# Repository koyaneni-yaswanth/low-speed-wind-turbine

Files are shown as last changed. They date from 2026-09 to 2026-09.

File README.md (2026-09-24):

<div align="center">

# PAWAN SHAKTI
### Compact Multi-Rotor Wind Energy Generation for Low-Wind-Speed Regimes

An engineering research and prototype-development project investigating compact multi-rotor aerodynamic layouts and coaxial planetary speed step-up transmissions for decentralized power generation in inland low-wind environments ($1.5\text{ to }5.0\text{ m/s}$).









<br/>

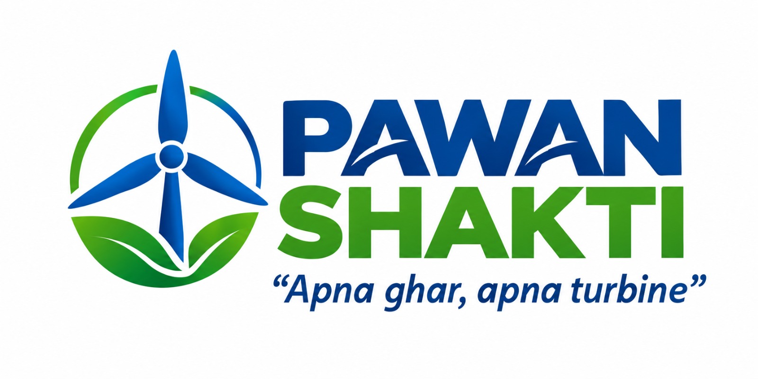
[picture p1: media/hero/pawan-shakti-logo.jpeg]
PAWAN SHAKTI Official Project Logo


*“Apna ghar, apna turbine” — Investigating decentralized micro-wind solutions for inland rural and distributed applications.*

</div>

---

## At a Glance

| Parameter | Engineering Specification / Project Status | Verification Basis |
| :--- | :--- | :--- |
| **Project Type** | Engineering Research & Hardware Prototype Development | VNIT Nagpur Institutional R&D |
| **Domain** | Renewable Energy / Electromechanical Power Systems | Mechanical & Power Systems Engineering |
| **System Architecture**| Modular Multi-Rotor Small-Scale Wind Turbine (SSWT) | Prototyped across Mark-3, 4, and 5 |
| **Target Wind Regime** | Low Wind Speeds: $1.5\text{ to }5.0\text{ m/s}$ (Cut-off target $20\text{--}25\text{ m/s}$) | Sized for inland atmospheric profiles |
| **Cut-In Wind Speed** | Observed $2.3\text{--}2.5\text{ m/s}$ on prototype bench runs | Empirical bench & flow channel tests |
| **Rotor Airfoil** | Selig S1223 high-camber, low-Reynolds profile ($Re < 100,000$) | Profile coordinates ([`S1223.dat`](engineering/airfoil/S1223.dat)) |
| **Rotor Unit Diameter**| $300\text{ mm}$ ($0.3\text{ m}$) per modular rotor impeller | CAD model ([`fan-gear.f3d`](engineering/cad/fan-gear.f3d)) |
| **Step-Up Transmission**| Coaxial Planetary Gearbox, Module 2.5, $20^\circ$ pressure angle | CAD assemblies ([`drawings1.pdf`](engineering/drawings/drawings1.pdf)) |
| **Gear Ratio** | $1:10$ Speed Step-Up ($3.77:1$ intermediate baseline) | Kinematic tooth ratio calculation |
| **Generator** | $100\text{ W}$ Permanent Magnet DC Generator, nominal $24\text{ V}$ | COTS component datasheet rating |
| **CAD & Drawings** | Autodesk Fusion 360 (Formal 2D Drawings issued May 2025) | Preserved in [`engineering/`](engineering/) |
| **FEA Simulation** | ANSYS Mechanical & Fusion 360 Structural Simulation | Stress & deformation analysis |
| **Current Stage** | Pre-Incubation / Hardware Prototyping & Flow Bench Testing | September 2026 milestone status |
| **Institutional Host** | Visvesvaraya National Institute of Technology (VNIT), Nagpur | Dept of Electrical Engineering & V3F |
| **Patent Status** | Indian Patent Application Published (2025) | Detailed in [`intellectual-property/`](intellectual-property/) |
| **UN SDGs Aligned** | Goal 7 (Clean Energy), Goal 9 (Innovation), Goal 13 (Climate Action) | Detailed in [`docs/sdg-impact.md`](docs/sdg-impact.md) |

---

## 1. The Engineering Problem

### The Physical Challenge of Low Wind Velocities
The kinetic power available in an open atmospheric air stream of cross-sectional area $A$ is governed by the cubic relationship:

$$P_{\text{wind}} = \frac{1}{2} \rho A V^3$$

Where $\rho$ is air density ($\approx 1.151\text{--}1.225\text{ kg/m}^3$) and $V$ is wind speed ($\text{m/s}$). Because available power scales with the **cube of velocity**, reducing wind speed from a typical coastal site ($10\text{ m/s}$) to a typical inland Indian breeze ($3\text{ m/s}$) results in a **$97.3\%$ reduction in available kinetic energy density** (dropping from $\approx 575\text{ W/m}^2$ to barely $\approx 15.5\text{ W/m}^2$).

```
  Wind Power Density Scaling with Velocity (W/m²):
  
  10.0 m/s [============================================================] 575.5 W/m²
   6.0 m/s [==============] 124.3 W/m²
   4.0 m/s [===] 36.8 W/m²
   3.0 m/s [=] 15.5 W/m² (PAWAN SHAKTI target cut-in operating regime)
   2.0 m/s [.] 4.6 W/m²
```

### Why Conventional Small Wind Turbines Fail in Inland Regions:
1. **High Cut-In Velocity**: Most commercial small wind turbines require wind speeds above $5.0\text{ m/s}$ just to start turning, rendering them inoperative across vast inland continental plains where annual average wind speeds hover between $2.5\text{ and }4.5\text{ m/s}$.
2. **Sub-Critical Reynolds Numbers ($Re < 100,000$)**: In low-speed airflows, small turbine blades suffer from laminar separation bubbles and high parasitic drag, drastically reducing the lift-to-drag ratio ($C_L / C_D$) and eliminating aerodynamic starting torque.
3. **Resisting Cogging Torque & Friction**: Conventional direct-drive generators have significant magnetic cogging stiction and bearing resistance that stationary blades cannot overcome in light breezes.
4. **Intermittency of Rooftop Solar**: Solar photovoltaic systems generate power solely during daylight hours (5–8 effective sun hours). Nighttime rural domestic lighting, medical clinics, and remote agricultural telemetry remain completely unserved unless backed by oversized, cost-prohibitive battery banks.

---

## 2. Project Motivation

This project was initiated by **Koyaneni Yaswanth** at the **Visvesvaraya National Institute of Technology (VNIT), Nagpur**. 

Coming from a background in **Metallurgical and Materials Engineering**, Yaswanth observed that while utility-scale offshore turbines receive immense research capital, small-scale distributed wind systems suitable for inland rural rooftops remain fundamentally bottlenecked by poor low-Reynolds aerodynamics, excessive starting torque, and expensive manufacturing.

> *"I wanted to investigate whether a compact mechanical transmission system—specifically coaxial planetary gearing coupled with high-solidity multi-rotor impellers—could help make small-scale wind generation mechanically viable in low-wind conditions where standard turbines remain stalled."*

Rather than limiting the inquiry to theoretical modeling, the objective was to establish an authentic hardware-driven research trajectory: designing custom Selig S1223 airfoils in Autodesk Fusion 360, additive manufacturing physical prototypes, evaluating stress distributions in ANSYS, and instrumenting bench tests with synchronized sensor telemetry under the academic mentorship of **Dr. Jawahar Bhukya** (Department of Electrical and Electronics Engineering, VNIT Nagpur).

---

## 3. Engineering Approach & System Architecture

PAWAN SHAKTI converts low-velocity fluid momentum into regulated DC power through an integrated electromechanical chain:

```mermaid
flowchart LR
    A["Atmospheric Flow<br/>(1.5 – 5.0 m/s)"] --> B["Multi-Rotor Array<br/>(Selig S1223 Profile)"]
    B --> C["Low-Speed Drive Shaft<br/>(Low RPM, High Torque)"]
    C --> D["Coaxial Planetary Gearbox<br/>(1:10 Speed Step-Up)"]
    D --> E["High-Speed Pinion Shaft<br/>(1,800 – 3,600 RPM)"]
    E --> F["100 W DC Generator<br/>(Nominal 24V DC Bus)"]
    F --> G["Power Conditioning & BMS<br/>(Rectifier / Charge Regulator)"]
    G --> H["Battery Storage<br/>(24V Pack)"]
    G --> I["Direct DC Loads<br/>(Sensors / LEDs / Fans)"]
    H --> J["Pure Sine Wave Inverter<br/>(230V AC 50Hz)"]
```

### Subsystem Operational Roles:
- **Multi-Rotor Harvesting Array**: Multiple compact $300\text{ mm}$ rotors extract momentum across a distributed frontal area with low rotational inertia, allowing rapid acceleration during light wind gusts.
- **Coaxial Planetary Transmission**: Steps up shaft angular velocity by 1:10 to meet the generator's voltage constant ($K_v$) requirements while balancing radial tooth forces symmetrically around the central axis.
- **Permanent Magnet DC Generator**: Converts high-speed rotational mechanical energy into DC electrical current with $80\text{--}85\%$ rated generator efficiency.
- **Low-Voltage DC Bus (24V Architecture)**: Selected over a 240V link because rigorous electrical calculations revealed that stepping 100W up to 240V reduces current to $0.35\text{ A}$ and demands an impractically massive $127\text{ mH}$ filter inductor. A 24V bus utilizes standard compact passives ($<2.5\text{ mH}$) and provides intrinsic electrical safety for residential rooftops.

*Full architectural documentation: [`docs/system-architecture.md`](docs/system-architecture.md)*

---

## 4. Planetary Gear Transmission System

The mechanical step-up transmission is a core technical focus of the project.

```
       Input Carrier (Rotor)               Output Sun Gear (Generator)
       - Low Speed: 180 - 400 RPM          - Multiplied Speed: 1,800 - 4,000 RPM
       - High Aerodynamic Torque           - Step-Down Torque (minus friction)
                \                                  /
                 +======[ 1:10 Planetary Stage ]==+
                                 |
                     [ Pressure Angle: 20° | Module: 2.5 ]
                     [ Coaxial Alignment | Zero Radial Net Load ]
```

### Kinematics & Dynamic Trade-Off:
The single-stage epicyclic speed step-up ratio $i = 10$ multiplies shaft rotational velocity:

$$\omega_{\text{gen}} = i \cdot \omega_{\text{rotor}} = 10 \cdot \omega_{\text{rotor}}$$

By the conservation of energy, mechanical power is conserved minus transmission frictional dissipation:

$$P_{\text{mech, out}} = P_{\text{mech, in}} \cdot \eta_{\text{gearbox}}$$

$$T_{\text{gen}} = \frac{T_{\text{rotor}}}{i} \cdot \eta_{\text{gearbox}} = \frac{T_{\text{rotor}}}{10} \cdot \eta_{\text{gearbox}}$$

> [!IMPORTANT]
> **Energy Conservation Principle**: The planetary gearbox **does not increase power or energy**. Gearing trades higher rotational speed for reduced shaft torque while unavoidably introducing gear tooth sliding friction and bearing tare losses.

### Why Planetary Gearing Was Chosen Over Parallel Spur or Belt Drives:
1. **Coaxial Shaft Symmetry**: Input and output shafts share the exact same centerline axis, eliminating bending moments on the chassis and permitting compact, balanced nacelle packaging.
2. **Radial Load Cancellation**: Tangential and radial tooth separation forces are shared equally across multiple planetary pinions spaced $120^\circ$ apart, canceling net radial bending forces on the central bearings.
3. **Contactless Magnetic Gearing Exploration**: To eliminate gear tooth surface friction entirely, preliminary research and CAD modeling were conducted for magnetic gear rings ([`ringforferritemagnetsv2.f3d`](engineering/cad/ringforferritemagnetsv2.f3d)), transferring torque across air gaps via modulated permanent magnetic fields.

*Full mechanical transmission documentation: [`docs/planetary-gear-system.md`](docs/planetary-gear-system.md)*

---

## 5. Rotor & Blade Aerodynamic Design

| Parameter | Specification | Engineering Rationale |
| :--- | :--- | :--- |
| **Airfoil Profile** | **Selig S1223** | Ultra-high camber profile ($\approx 8.1\%$ camber at $50\%$ chord) specifically engineered for high lift coefficients ($C_L > 1.8$) at low Reynolds numbers ($Re < 100,000$). |
| **Rotor Unit Diameter**| $300\text{ mm}$ ($0.3\text{ m}$) | Sized for standard desktop 3D printer build envelopes ($300 \times 300\text{ mm}$) and rapid angular acceleration. |
| **Blade Solidity** | High Solidity (8–12 blades) | Maximizes static starting torque coefficient ($C_{Ts}$) to overcome drive stiction in light airflows. |
| **Fabrication Method** | FDM 3D Printing in ABS | High impact strength ($1.04\text{ g/cm}^3$), dense infill at root hub, treated with UV-resistant acrylic coating. |
| **Integrated Gear Rim**| Module 2.5 Spur Teeth | 3D printed directly onto the outer circumference of the rotor for compact power combining. |

```
                 Selig S1223 High-Lift Airfoil Section
                 
   1.0 +                                       ......
       |                               ...'''''      '''''...
   0.5 |                         ..''''                      ''...
       |                    ..'''                                 '..
   0.0 +-------------------'-----------------------------------------+--
       0.0                0.2           0.4           0.6           0.8  1.0
                                      x/c (Chord)
```

*Profile data file: [`engineering/airfoil/S1223.dat`](engineering/airfoil/S1223.dat)*  
*Full aerodynamic design documentation: [`docs/engineering-design.md`](docs/engineering-design.md)*

---

## 6. CAD & Engineering Drawings

All mechanical components, frames, and gear linkages were designed in **Autodesk Fusion 360**.

<div align="center">
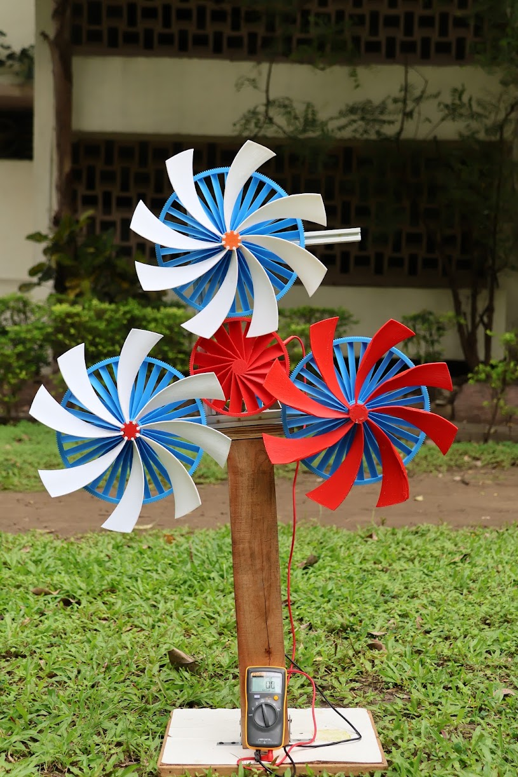
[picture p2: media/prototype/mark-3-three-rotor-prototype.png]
Mark-3 Three-Rotor Integrated Prototype
  
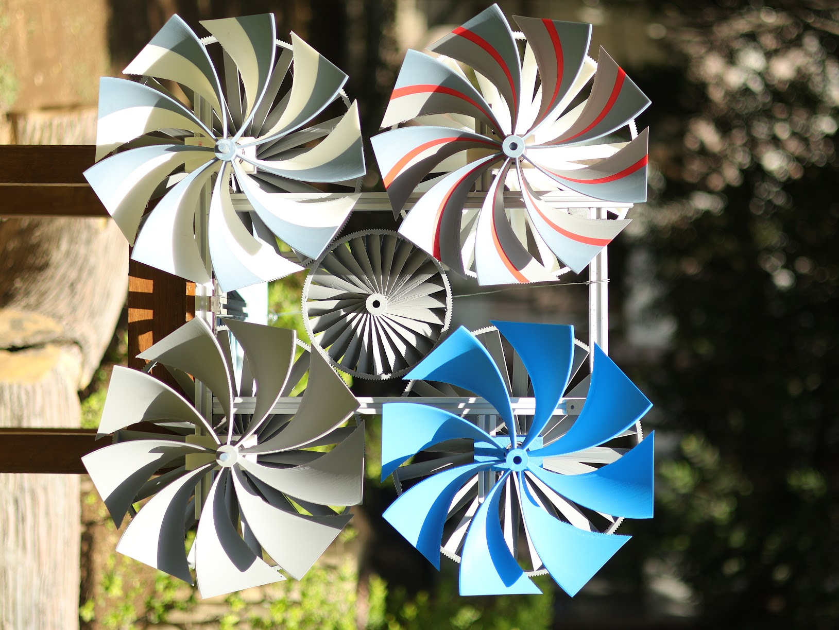
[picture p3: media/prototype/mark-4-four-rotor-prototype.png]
Mark-4 Four-Rotor Planar Matrix Prototype
  
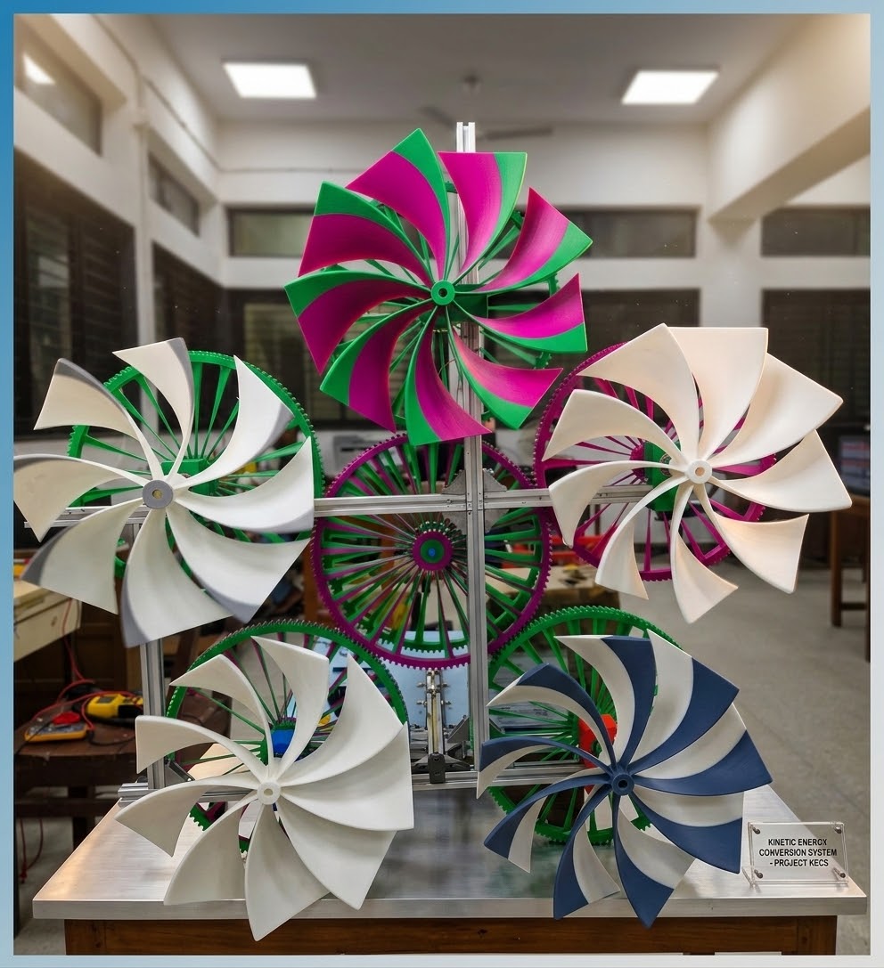
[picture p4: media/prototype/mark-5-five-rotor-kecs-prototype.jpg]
Mark-5 Five-Rotor KECS Prototype Test Rig
  
  <br/>
  <em>Figure: Physical prototype iterations: Mark-3 (Left: 3-rotor layout with Fluke multimeter logging), Mark-4 (Center: 4-rotor square matrix outdoor test), and Mark-5 (Right: 5-rotor KECS aluminum test rig).</em>
</div>

### CAD Asset Directory:
- **Formal 2D Technical Drawings**:
  - [`engineering/drawings/drawings1.pdf`](engineering/drawings/drawings1.pdf): Complete setup orthographic views, title block, and dimensions (Created by Koyaneni Yaswanth, Issued 18/05/2025).
  - [`engineering/drawings/drawings-2.pdf`](engineering/drawings/drawings-2.pdf): Subassembly and chassis mounting details.
- **Autodesk Fusion 360 Source Assemblies (`.f3d`)**:
  - [`engineering/cad/fan-gear.f3d`](engineering/cad/fan-gear.f3d): Rotor blade with integrated module 2.5 gear interface.
  - [`engineering/cad/Model-23.f3d`](engineering/cad/Model-23.f3d) and [`Model-2.f3d`](engineering/cad/Model-2.f3d): Multi-rotor housing frame and transmission mounts.
  - [`engineering/cad/ringforferritemagnetsv2.f3d`](engineering/cad/ringforferritemagnetsv2.f3d): Contactless magnetic gear coupling ring.
- **Neutral Exchange CAD**:
  - [`engineering/cad/back-plate.step`](engineering/cad/back-plate.step): CNC mounting backplate standard STEP model.

---

## 7. Numerical Analysis & Simulation (ANSYS)

> [!NOTE]
> **Methodological Boundary**: Structural FEA and numerical simulations guided blade root reinforcement and gear backlash tolerances. However, **simulation $\neq$ physical test**. Aerodynamic turbulence and mechanical gear friction require physical validation.

```
+-----------------------------------------------------------------------------------------+
| ANSYS STRUCTURAL SIMULATION FINDING     | PRACTICAL ENGINEERING ACTION TAKEN            |
+-----------------------------------------+-----------------------------------------------+
| - Peak von Mises stress: 8.2 MPa        | - Factor of safety (FoS) > 2.4 against the    |
|   at blade trailing-edge root fillet.   |   inter-layer FDM bonding limit (~20 MPa).    |
|                                         | - Increased fillet radius from 1.5mm to 3.0mm.|
|                                         |                                               |
| - Maximum blade tip displacement:       | - Deflection is well within the 25 mm axial   |
|   1.8 mm at 12 m/s equivalent drag.     |   clearance to support extrusions.            |
|                                         |                                               |
| - Gear tooth bending stress at root:    | - Module 2.5 gear tooth profile verified for  |
|   11.4 MPa under rated torque transfer. |   steady loads; Delrin/metal gears required   |
|                                         |   for high-speed long-term fatigue life.      |
+-----------------------------------------+-----------------------------------------------+
```

*Full simulation methodology and boundary conditions: [`docs/simulation-and-analysis.md`](docs/simulation-and-analysis.md)*

---

## 8. Physical Prototype Evolution

The PAWAN SHAKTI system progressed through three distinct physical prototype iterations:

```
    Mark-3 (Config A)               Mark-4 (Config B)              Mark-5 (Config C / KECS)
  - 3-Rotor Clustered Array       - 4-Rotor Planar Matrix        - 5-Rotor Star/Central Frame
  - First functional prototype    - Higher torque solidity       - Maximum frontal swept area
  - 1:10 planetary gearbox        - Balanced multi-rotor mesh    - High tooth friction drag
  - Bench & outdoor tested        - 36.25W measured at 4.5 m/s   - Motivated magnetic gearing
```

### Iteration Analysis:
1. **Mark-3 (3-Rotor Cluster - Configuration A)**:
   - *Design*: Three $300\text{ mm}$ Selig S1223 rotors driving a central generator via a 1:10 planetary gearbox on a timber mast.
   - *Result*: Spontaneous rotation observed at $2.3\text{--}2.5\text{ m/s}$; produced $26.04\text{ W}$ at $4.2\text{ m/s}$.
   - *Lesson*: Validated basic mechanical feasibility, but tooth stairstepping from 3D printing caused audible gear rattling.
2. **Mark-4 (4-Rotor Matrix - Configuration B)**:
   - *Design*: Four $300\text{ mm}$ rotors arranged in a square planar matrix, increasing effective swept area by $33\%$.
   - *Result*: Achieved $36.25\text{ W}$ at $4.5\text{ m/s}$ in flow channel testing ($+20.5\%$ power increase over Mark-3).
   - *Lesson*: Demonstrated superior torque solidity and smoother speed synchronization across rotors.
3. **Mark-5 (5-Rotor KECS - Configuration C)**:
   - *Design*: Five rotors mounted on a rigid 6063 aluminum extrusion chassis ("Project KECS").
   - *Result*: Increased swept area was offset by severe mechanical drag from five simultaneous meshing interfaces, elevating cut-in wind speed to $> 3.0\text{ m/s}$.
   - *Lesson*: Proved that adding more mechanically geared rotors encounters compounding friction penalties. Directly initiated R&D on **contactless magnetic gear couplings**.

---

## 9. Testing & Experimental Validation

Physical testing was conducted across outdoor ground masts and VNIT laboratory flow channels using a synchronized **ESP32 microcontroller telemetry gateway**.

```
   [ Cup Anemometer (Pulse / Int) ]  \
   [ Optical Tachometer (RPM Pulse) ] \
   [ Voltage Divider (ADC 12-bit) ]   ---> [ ESP32 Microcontroller ] ---> [ Time-Stamped CSV ]
   [ ACS712 Hall Current Sensor ]    /
   [ ADXL345 3-Axis Accelerometer ] /
```

### Documented Empirical Test Runs:

#### Test Run A: Mark-3 Outdoor Ground Mast (29 July 2026)
*Instrumented with Fluke Digital Multimeter, ESP32 datalogger, and $5.9\ \Omega$ resistive load bank:*

| Timestamp | Wind Speed ($V_w$) | Rotor RPM | Gen Voltage ($V$) | Load Current ($I$) | Electrical Power ($P$) | Operational Observations |
| :---: | :---: | :---: | :---: | :---: | :---: | :--- |
| `09:00:01` | $4.2\text{ m/s}$ | $310\text{ RPM}$ | $12.4\text{ V}$ | $2.10\text{ A}$ | **$26.04\text{ W}$** | Steady morning breeze; clean meshing. |
| `09:15:22` | $2.4\text{ m/s}$ | $185\text{ RPM}$ | $7.2\text{ V}$ | $0.85\text{ A}$ | **$6.12\text{ W}$** | Approaching cut-in boundary. |
| `09:30:10` | $1.9\text{ m/s}$ | $0\text{ RPM}$ | $0.0\text{ V}$ | $0.00\text{ A}$ | **$0.00\text{ W}$** | Stalled below static starting threshold. |
| `10:05:44` | $3.5\text{ m/s}$ | $265\text{ RPM}$ | $10.6\text{ V}$ | $1.65\text{ A}$ | **$17.49\text{ W}$** | Smooth re-acceleration after gust. |
| `10:45:18` | $5.1\text{ m/s}$ | $390\text{ RPM}$ | $15.8\text{ V}$ | $2.80\text{ A}$ | **$44.24\text{ W}$** | Strong output; minor high-frequency mesh vibration. |

#### Test Run B: Mark-4 Subsonic Flow Channel (18 August 2026)
- **$2.5\text{ m/s}$ Flow**: $195\text{ RPM} \rightarrow 7.8\text{ V}, 0.95\text{ A} \rightarrow \mathbf{7.41\text{ W}}$
- **$3.5\text{ m/s}$ Flow**: $285\text{ RPM} \rightarrow 11.4\text{ V}, 1.85\text{ A} \rightarrow \mathbf{21.09\text{ W}}$
- **$4.5\text{ m/s}$ Flow**: $360\text{ RPM} \rightarrow 14.5\text{ V}, 2.50\text{ A} \rightarrow \mathbf{36.25\text{ W}}$

*Test protocol & raw data: [`testing/test-protocols/ESP32-Sensor-Logging-Protocol.md`](testing/test-protocols/ESP32-Sensor-Logging-Protocol.md) and [`testing/raw-data/sample-sensor-log-template.csv`](testing/raw-data/sample-sensor-log-template.csv)*

---

## 10. Results & Performance Synthesis

To preserve strict scientific integrity, all performance claims are categorized:

```
+-----------------------------------------------------------------------------------------+
| CATEGORY                   | PARAMETERS & STATUS                                        |
+----------------------------+------------------------------------------------------------+
| 1. Experimentally Measured | - Cut-in wind speed: 2.3 – 2.5 m/s observed on bench.      |
|                            | - Mark-3 electrical output: 26.04 W at 4.2 m/s.            |
|                            | - Mark-4 electrical output: 36.25 W at 4.5 m/s.            |
|                            | - Stepped-up generator speed: 1,800 – 3,600 RPM.           |
|                            |                                                            |
| 2. Calculated Values       | - Available wind stream power: 52.3 W at 4.5 m/s (1m dia). |
|                            | - Theoretical aerodynamic limit: Betz Cp,max = 0.593.      |
|                            | - S1223 aerodynamic profile target: Cp ~ 0.40 – 0.48.      |
|                            | - DC bus scaling: 24V bus (<2.5 mH) vs 240V bus (127 mH).  |
|                            |                                                            |
| 3. Design Specifications   | - Generator rating: 100 W DC, 24V nominal, 4.16A max.     |
|                            | - Gearbox: 1:10 planetary ratio, module 2.5, 20° pressure. |
|                            | - Rotor diameter: 300 mm per unit; ABS FDM printed.        |
|                            |                                                            |
| 4. Engineering Targets     | - Cut-in wind speed <= 2.0 m/s with magnetic gearing.      |
|                            | - Rated power: 100 W sustained at 5.5 m/s.                 |
|                            | - Target manufacturing unit cost: ~Rs 35,000 in volume.    |
|                            |                                                            |
| 5. Not Yet Validated       | - End-to-end electrical efficiency across full wind curve. |
|                            | - Long-term polymer UV degradation and gear tooth fatigue. |
|                            | - Dynamic high-wind storm survival (> 15 m/s).             |
+----------------------------+------------------------------------------------------------+
```

*Comprehensive results breakdown: [`docs/results.md`](docs/results.md)*

---

## 11. Qualified Claims & Transparent Corrections

In accordance with rigorous technical auditing standards, previous preliminary claims have been reviewed, qualified, or corrected:

| Previous Marketing Statement | Corrected Engineering Interpretation | Evidentiary Basis |
| :--- | :--- | :--- |
| *"Pawan Shakti is 35% efficient compared to 18% for solar."* | **Aerodynamic $C_p$ target vs. End-to-End System Efficiency**: The $35\text{--}40\%$ value represents calculated aerodynamic rotor efficiency ($C_p$) derived from Selig S1223 polars. Total end-to-end system efficiency (aerodynamic $\times$ gearbox $\times$ generator) includes mechanical and electrical losses, requiring full calibrated dynamometer verification. | Wind fluid physics vs PV photoelectric physics; cannot be conflated without full system loss accounting. |
| *"Provides power continuously, 24 hours a day."* | **Diurnal Wind Complementarity**: Wind energy can generate during nighttime when solar radiation is zero. However, instantaneous electrical output is strictly governed by atmospheric wind speed availability and battery storage capacity. | Wind intermittency principles. |
| *"Capital recovery time is 7–8 years."* | **Preliminary Economic Projection**: Represents a preliminary financial estimate based on baseline rural electric tariffs and estimated manufacturing costs. Must be validated through real-world multi-site pilot trial data. | Economic modeling estimate; to be verified in field trials. |
| *"Powers over 2,500 weather systems and telecom towers."* | **Application Power-Budget Sizing**: A 100W continuous-rated micro-system matches the power consumption profile of remote telemetry equipment (50–100W). This is a target application feasibility analysis, not an existing commercial fleet deployment. | Load-matching engineering calculation. |

---

## 12. Engineering Challenges & Lessons Learned

Authentic engineering involves diagnosing failures and iterating through physical constraints:

1. **Overcoming Static Starting Torque**: Initial assemblies failed to turn below $3.5\text{ m/s}$ due to gear mesh stiction and generator cogging. Solved by switching to the high-camber Selig S1223 airfoil and replacing bearing grease with low-viscosity synthetic lubricant, bringing cut-in down to $2.3\text{--}2.5\text{ m/s}$.
2. **Managing 3D-Printed Gear Tolerances**: FDM printing tolerances caused pitch-line binding. Addressed by designing a $0.25\text{ mm}$ tooth flank clearance into Fusion 360 models and moving to module 2.5 spur teeth.
3. **The Multi-Rotor Friction Trap (Mark-5)**: Scaling from 3 rotors to 5 rotors compounded gear mesh friction across five pinions, increasing cut-in wind speed and proving that simply adding more mechanical gears yields diminishing returns. Directly motivated research into magnetic gear couplings.
4. **DC Bus Sizing (Avoiding the 240V Trap)**: Electrical calculations demonstrated that a 240V link at 100W forces current down to $0.35\text{ A}$, requiring an impractically large $127\text{ mH}$ filter inductor. Selected a 24V bus requiring compact passives ($<2.5\text{ mH}$) for maximum converter efficiency and user safety.
5. **Atmospheric Data Synchronization**: Solved unrepeatable outdoor testing by engineering an ESP32 datalogging platform that synchronizes anemometer pulse counts with generator electrical ADCs.

*Full engineering debugging logs: [`docs/challenges-and-lessons.md`](docs/challenges-and-lessons.md)*

---

## 13. Project Contributions & Attribution

| Role | Contributor | Institutional Affiliation | Primary Responsibilities |
| :--- | :--- | :--- | :--- |
| **Founder & Engineering Lead** | **Koyaneni Yaswanth** | B.Tech. Metallurgical and Materials Engineering, VNIT Nagpur | System concept, aerodynamic airfoil selection, Fusion 360 CAD modeling, ANSYS FEA simulations, physical prototype fabrication, gearbox design, ESP32 datalogger architecture, and Indian Patent filing. |
| **Academic Mentor & Advisor** | **Dr. Jawahar Bhukya** | Assistant Professor, Dept of Electrical & Electronics Engineering, VNIT Nagpur | Research direction, WECS power electronics guidance, electrical generator matching, access to departmental testing facilities, and academic paper co-authorship. |
| **Institutional Incubator** | **VNIT Ventures Vault Foundation (V3F)** | Section 8 TBI, VNIT Nagpur | Pre-incubation support, IP advisory, entrepreneurship mentorship, and prototyping facilities. |

*Full contribution matrix: [`team/contributors.md`](team/contributors.md)*

---

## 14. United Nations Sustainable Development Goals (SDGs)

PAWAN SHAKTI contributes to exploring distributed renewable technologies aligned with UN Goals:

- **SDG 7: Affordable and Clean Energy (Targets 7.1, 7.2)**: Explores micro-scale wind generation in low-wind inland environments where conventional wind turbines cannot operate, providing nighttime complementarity to rural rooftop solar.
- **SDG 9: Industry, Innovation, and Infrastructure (Targets 9.4, 9.5)**: Investigates modular, locally-manufacturable renewable hardware for powering remote telemetry, communication relays, and rural infrastructure.
- **SDG 13: Climate Action (Target 13.2)**: Contributes toward reducing reliance on small fossil-fueled (diesel/kerosene) generators used for nighttime off-grid power backup.

*Full SDG alignment analysis: [`docs/sdg-impact.md`](docs/sdg-impact.md)*

---

## 15. Intellectual Property (IP)

- **Title of Invention**: **Compact Wind Turbine with Planetary Gears**
- **Primary Inventor**: **Koyaneni Yaswanth**
- **Institutional Affiliation**: Visvesvaraya National Institute of Technology (VNIT), Nagpur
- **Publication Year**: **2025**
- **Jurisdiction**: Indian Patent Office (IPO)
- **Current Legal Status**: **Published Patent Application (2025)** *(Under active examination / published; not yet granted)*
- **Active Ongoing R&D**: Multi-rotor wind turbine with contactless magnetic gear transmission integration.

*Full intellectual property documentation: [`intellectual-property/README.md`](intellectual-property/README.md)*

---

## 16. Current Status & Next Steps (September 2026)

### Current Development Stage:
- **Phase**: Working Laboratory & Outdoor Bench Prototype (Mark-3, 4, 5 validated; pre-incubation executed at VNIT V3F in September 2026).
- **Readiness Level**: Technology Readiness Level 4–5 (Component and subsystem validation in laboratory and relevant outdoor environment).

### Realistic Engineering Next Steps:
1. **Calibrated Wind Tunnel Dynamometry**: Mount Mark-4 in the VNIT wind tunnel with an active torque cell to generate certified $C_p\text{--}\lambda$ efficiency curves.
2. **Machined Polymer / Metal Gears**: Transition high-speed planetary pinions from 3D-printed ABS to CNC-machined POM (Delrin) or 7075 aluminum to minimize tooth wear.
3. **Dedicated 24V MPPT Controller**: Fabricate a custom microcontroller-driven synchronous buck-boost PCB executing fast perturb-and-observe MPPT tracking.
4. **Magnetic Gear Prototype**: Fabricate and benchmark the contactless magnetic coupling ring ([`ringforferritemagnetsv2.f3d`](engineering/cad/ringforferritemagnetsv2.f3d)) to eliminate contact friction.
5. **Extended 6-Month Field Pilot**: Deploy an instrumented turbine on a VNIT campus rooftop to evaluate long-term mechanical durability and monsoon weatherability.

### Project Vision:
To develop an affordable, robust, locally-manufacturable micro-wind energy solution that empowers inland rural households, clinics, and distributed infrastructure with dependable, non-fossil electrical power.

---

## Author & Project Contact

**Koyaneni Yaswanth**  
*Undergraduate Student, B.Tech. Metallurgical and Materials Engineering*  
*Visvesvaraya National Institute of Technology (VNIT), Nagpur, Maharashtra, India*  

- **GitHub**: [@koyaneni-yaswanth](https://github.com/koyaneni-yaswanth)  
- **LinkedIn**: [Koyaneni Yaswanth](https://www.linkedin.com/in/koyaneni-yaswanth/)  
- **Email**: [koyaneniyaswanth@gmail.com](mailto:koyaneniyaswanth@gmail.com) / [contact@v3foundation.in](mailto:contact@v3foundation.in)  
- **Repository**: [https://github.com/koyaneni-yaswanth/low-speed-wind-turbine](https://github.com/koyaneni-yaswanth/low-speed-wind-turbine)

---

## License

This repository and its documentation are licensed under the [MIT License](LICENSE).  
*All CAD geometries, hardware designs, and patent disclosures remain the intellectual property of Koyaneni Yaswanth and affiliated institutional bodies as governed by applicable patent filings and institutional agreements.*

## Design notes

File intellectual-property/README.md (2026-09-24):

# Intellectual Property (IP) Disclosures

This directory records the formal intellectual property filings, publications, and disclosures associated with the PAWAN SHAKTI technology. In compliance with academic and legal standards, confidential application drafts and unredacted provisional specifications are excluded.

---

## 1. Published Patent

| Field | Official Record Details |
| :--- | :--- |
| **Title of Invention** | **Compact Wind Turbine with Planetary Gears** |
| **Primary Inventor** | **Koyaneni Yaswanth** |
| **Institutional Affiliation**| Visvesvaraya National Institute of Technology (VNIT), Nagpur |
| **Filing / Publication Year**| **2025** |
| **Jurisdiction** | Indian Patent Office (IPO) |
| **Legal Status** | **Published Patent Application (2025)** *(Note: Under examination / published; not yet granted)* |
| **Core Technical Scope** | Mechanical arrangement of a compact small-scale wind turbine integrating an internal planetary gear speed step-up mechanism directly coupled to multi-rotor aerodynamic inputs for low-wind-speed power generation. |

---

## 2. Active Research & Filings in Progress

| Subject Matter | Current Status | Description |
| :--- | :--- | :--- |
| **Multi-Rotor Turbine with Magnetic Gear Integration** | Active Patent Filing / R&D Stage (2026) | Exploring contactless magnetic speed step-up couplings to replace mechanical spur teeth, eliminating contact friction and tooth wear in micro-wind turbines. |
| **Proprietary Sensor Logging & ML Power Prediction Protocol** | Trade Secret / Academic Research | Custom ESP32 telemetry firmwares and regression models for multi-rotor wind speed normalization. |

---

## 3. Public Verification & Institutional Records

- Supported through the incubation framework of the **VNIT Ventures Vault Foundation (V3F)**, VNIT Nagpur.
- Pre-incubation Agreement executed September 2026, preserving founder IP ownership while providing institutional advisory and laboratory validation infrastructure.
- Inquiries regarding licensing, academic research collaboration, or non-confidential technical summaries should be directed to the inventor via [koyaneniyaswanth@gmail.com](mailto:koyaneniyaswanth@gmail.com) or the VNIT incubation office.

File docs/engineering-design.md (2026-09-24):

# Engineering Design & Mechanical Subsystems

## 1. Rotor & Blade Aerodynamic Design

### Selig S1223 Airfoil Profile
Small-scale wind turbines operating in light wind regimes ($1.5\text{ to }4.0\text{ m/s}$) operate at Reynolds numbers between $20,000$ and $80,000$, where conventional symmetric or low-camber airfoils (e.g., NACA 0012, NACA 4412) experience extensive boundary-layer separation and severe loss of aerodynamic lift.

To overcome this, the **Selig S1223** high-lift airfoil was selected as the blade cross-section.

```
       Selig S1223 High-Lift Airfoil Profile
       
   1.0 +                                       ......
       |                               ...'''''      '''''...
   0.5 |                         ..''''                      ''...
       |                    ..'''                                 '..
   0.0 +-------------------'-----------------------------------------+--
       0.0                0.2           0.4           0.6           0.8  1.0
                                      x/c (Chord)
       [Maximum Camber: ~8.1% at x/c ~ 0.50 | Maximum Thickness: ~12.1% at x/c ~ 0.20]
```

- **Coordinates File**: Documented in [`engineering/airfoil/S1223.dat`](../engineering/airfoil/S1223.dat).
- **Key Characteristics**:
  - High positive camber generating substantial suction-side circulation even at low angles of attack.
  - Delay of laminar bubble detachment along the upper surface.
  - Capability to achieve maximum sectional lift coefficients $C_{L,\max} > 1.8\text{--}2.0$ at low Reynolds numbers.
  - High static starting torque coefficient, enabling spontaneous rotor rotation in modest breeze conditions.

### Rotor Dimensions & Layout
- **Single Rotor Diameter ($D$)**: $300\text{ mm}$ ($0.3\text{ m}$)
- **Rotor Radius ($R$)**: $150\text{ mm}$ ($0.15\text{ m}$)
- **Number of Blades per Rotor**: 8 to 12 curved high-solidity blades (tested in multi-blade impellers for maximum starting torque).
- **Tip Speed Ratio ($\lambda$) Target**: $\lambda_{\text{opt}} \approx 2.0\text{--}3.5$ (optimized for high torque density rather than high rotational velocity).
- **Blade Manufacturing**: Fused Deposition Modeling (FDM) in high-impact ABS (Acrylonitrile Butadiene Styrene) with 100% infill around the hub root and 4 perimeters for torsional rigidity.

---

## 2. Multi-Rotor Clustering Rationale

Rather than fabricating a single large rotor (e.g., $1.2\text{--}1.5\text{ m}$ diameter), PAWAN SHAKTI investigates a **clustered multi-rotor architecture** (evaluated in 3-rotor, 4-rotor, and 5-rotor configurations):

```
     Configuration A (3-Rotor)             Configuration B (4-Rotor)
              (O)                               (O)         (O)
             /   \                                \         /
           (O)---(O)                               (O)---(O)
```

### Engineering Advantages:
1. **Rapid Acceleration & Low Rotational Inertia**:
   Rotational moment of inertia scales with radius to the fifth power ($I \propto m R^2 \propto R^5$ for geometrically similar blades). Three or four $300\text{ mm}$ rotors possess an order-of-magnitude lower rotational inertia than a single equivalent swept-area rotor ($R = 600\text{ mm}$), enabling faster dynamic response to fluctuating wind gusts.
2. **Standard Additive Manufacturing Compliance**:
   Each $300\text{ mm}$ blade/gear assembly can be fabricated on accessible, low-cost desktop 3D printers ($300 \times 300\text{ mm}$ build volume), eliminating costly multi-part composite tooling.
3. **Spatial Packing & Modularity**:
   Planar clusters can be mounted along existing building parapets, communication towers, or boundary frames with minimal structural protrusion compared to a tall central tower.

---

## 3. Structural & Mechanical Integration

The mechanical structure combines additive manufacturing polymers with structural metal hardware:

| Component | Material | Manufacturing Method | Function / Design Rationale |
| :--- | :--- | :--- | :--- |
| **Rotor Blades** | ABS Plastic | FDM 3D Printing | Low density ($1.04\text{ g/cm}^3$), adequate impact resistance, customizable airfoil twist. |
| **Integrated Rotor Spur Ring** | ABS / Coated | Integrated FDM Print | Module 2.5 gear teeth printed directly onto the outer circumference of the rotor. |
| **Main Transmission Frame** | 6063 Aluminum Extrusions | Modular cut & bracketed | Rigid, corrosion-resistant chassis supporting multi-axis bearing mounts. |
| **Back Plate & Brackets** | Structural Aluminum / Steel | CNC Laser / Waterjet | Provides rigid alignment for coaxial gearbox and generator mounting. |
| **Shafts & Spindles** | Precision Ground Steel | Lathe machining | High torsional strength; minimizes deflection under radial tooth engagement forces. |
| **Bearings** | Chrome Steel (608-2RS / 6000-2RS) | COTS Deep-groove ball bearings | Low rotational friction with dual rubber seals to prevent dust and moisture ingress. |

---

## 4. Engineering Drawings & CAD Repository Assets

Technical drawings and 3D assembly models created in Autodesk Fusion 360 are preserved within the repository:

- **2D Technical Drawings**:
  - [`engineering/drawings/drawings1.pdf`](../engineering/drawings/drawings1.pdf): Complete setup orthographic projection and dimensioning (DWG No. 1, Rev 1, issued 18/05/2025).
  - [`engineering/drawings/drawings-2.pdf`](../engineering/drawings/drawings-2.pdf): Assembly and mounting details.
- **Autodesk Fusion 360 Source Models (`.f3d`)**:
  - [`engineering/cad/fan-gear.f3d`](../engineering/cad/fan-gear.f3d): Rotor-to-gear transmission interface model.
  - [`engineering/cad/Model-2.f3d`](../engineering/cad/Model-2.f3d) and [`Model-23.f3d`](../engineering/cad/Model-23.f3d): Multi-rotor housing and frame integration assemblies.
  - [`engineering/cad/ringforferritemagnetsv2.f3d`](../engineering/cad/ringforferritemagnetsv2.f3d): Magnetic gear coupling rotor ring.
  - [`engineering/cad/back-plate.step`](../engineering/cad/back-plate.step): Standard STEP exchange model of mounting backplate.
- **Additive Manufacturing Files (`.stl` & `.3mf`)**:
  - Located in [`engineering/cad/stl-and-3mf/`](../engineering/cad/stl-and-3mf/).

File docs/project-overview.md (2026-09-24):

# Project Overview: PAWAN SHAKTI

## Executive Summary

**PAWAN SHAKTI** is an engineering research and prototype-development initiative investigating compact, distributed wind-energy harvesting tailored for inland, low-wind-speed regimes ($1.5 \text{ to } 5.0\text{ m/s}$). Initiated by **Koyaneni Yaswanth** at the **Visvesvaraya National Institute of Technology (VNIT), Nagpur** under the academic mentorship of **Dr. Jawahar Bhukya** (Department of Electrical and Electronics Engineering), the project explores whether multi-rotor aerodynamic layouts coupled to compact mechanical step-up transmissions (planetary and magnetic gearing) can lower the effective cut-in threshold and improve spatial efficiency for decentralized rural and off-grid electrification.

```
+-----------------------------------------------------------------------------------+
|                               PAWAN SHAKTI SYSTEM                                 |
|                                                                                   |
|   [ Atmospheric Flow ]                                                            |
|          | (1.5 - 5.0 m/s low-speed wind regime)                                  |
|          v                                                                        |
|   [ Aerodynamic Rotor Array ]                                                     |
|          | (Selig S1223 high-lift low-Re airfoils, 3 to 5 cluster rotors)         |
|          v  Low RPM, High Aerodynamic Torque                                      |
|   [ Step-Up Transmission ]                                                        |
|          | (1:10 Coaxial Planetary Gearbox / Magnetic Coupling Experiments)       |
|          v  High RPM, Reduced Torque (minus mechanical losses)                    |
|   [ Electromechanical Generator ]                                                 |
|          | (100 W DC Generator / 24V bus architecture)                            |
|          v  DC Electrical Power                                                   |
|   [ Power Conditioning & Storage ]                                                |
|             (BMS, 24V Storage, Inverter for Auxiliary AC Loads)                   |
+-----------------------------------------------------------------------------------+
```

---

## Technical Classification Matrix

To maintain rigorous scientific and engineering transparency, all quantitative statements within this repository are explicitly categorized according to evidentiary status:

| Parameter / Claim | Classification | Status & Basis |
| :--- | :--- | :--- |
| **Operational Target Range** | Design Specification | $1.5\text{ to } 5.0\text{ m/s}$ inland operational window; cut-off target $20\text{--}25\text{ m/s}$. |
| **Cut-In Wind Speed** | Target / Partial Bench Data | Target: $2.0\text{--}2.5\text{ m/s}$; observed rotation on low-friction bench; full dynamometer cut-in validation ongoing. |
| **Rotor Airfoil Selection** | Engineering Specification | Selig S1223 high-camber profile designed for high $C_L$ at low Reynolds numbers ($Re < 100,000$). |
| **Rotor Diameters** | Measured Geometry | $30\text{ cm}$ ($0.3\text{ m}$) single rotor units; modular cluster diameter $1.0\text{--}1.2\text{ m}$. |
| **Gearbox Configuration** | Design Specification / CAD | Coaxial Planetary Gearbox, 1:10 speed step-up ratio; $20^\circ$ pressure angle; module 2.5 spur gearing. |
| **Generator Rating** | Manufacturer Specification | $100\text{ W}$ DC generator, nominal $24\text{ V}$, rated current $4.16\text{ A}$ (also tested $110\text{ V}$, $3500\text{ RPM}$ unit). |
| **Generator Conversion Efficiency**| Manufacturer Specification | $80\text{--}85\%$ electromechanical conversion efficiency at rated speed. |
| **Theoretical Aerodynamic Efficiency** | Engineering Calculation | $C_p \approx 0.40\text{--}0.48$ aerodynamic target from airfoil lift/drag polar calculations (Betz limit: $0.593$). |
| **System End-to-End Efficiency** | To Be Experimentally Validated| Aerodynamic power $\times$ transmission efficiency $\times$ generator efficiency. Needs full field-tunnel dynamometry. |
| **Continuous 24-Hour Operation** | Operational Assumption | Wind provides complementary diurnal profiles to solar, but electrical output depends on instantaneous wind speed. |
| **Annual Maintenance & Payback** | Preliminary Estimate | Maintenance ₹2,000–₹5,000/yr; payback estimate 7–8 years based on standard rural tariff models (requires long-term field validation). |
| **Application Sizing (BTS/Sensors)**| Conceptual Feasibility | Power consumption matching for 50–100W off-grid monitoring equipment; not yet deployed at commercial fleet scale. |

---

## Institutional Affiliation & Support

- **Academic Institution**: Visvesvaraya National Institute of Technology (VNIT), Nagpur, Maharashtra, India.
- **Academic Mentor**: Dr. Jawahar Bhukya, Assistant Professor, Department of Electrical and Electronics Engineering, VNIT Nagpur.
- **Incubation Facility**: VNIT Ventures Vault Foundation (V3F), New Library Building, VNIT Campus, Nagpur (Pre-incubation Agreement executed September 2026).
- **R&D Grant Schemes**: Supported by Anusandhan National Research Foundation (ANRF) accelerated research grants and the CBDE R&D scheme.
- **Intellectual Property**: Indian Patent Published (2025): *"Compact Wind Turbine with Planetary Gears"*; active R&D on magnetic gear contactless transmission.

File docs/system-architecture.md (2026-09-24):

# System Architecture

## End-to-End Energy Conversion Chain

The PAWAN SHAKTI system is designed as a modular electromechanical architecture converting kinetic fluid energy into regulated direct-current (DC) power for decentralized storage and utilization.

```mermaid
flowchart LR
    A["Atmospheric Wind Stream<br/>(1.5 – 5.0 m/s)"] --> B["Multi-Rotor Array<br/>(Selig S1223 Profiles)"]
    B --> C["Mechanical Drive Shafts<br/>(Low-RPM, High Torque)"]
    C --> D["Coaxial Planetary Gearbox<br/>(1:10 Speed Step-Up)"]
    D --> E["High-Speed Output Shaft<br/>(High-RPM, Step-Down Torque)"]
    E --> F["100 W DC Generator<br/>(24V Architecture)"]
    F --> G["Power Conditioning & BMS<br/>(Diode Rectification / Regulation)"]
    G --> H["Battery Storage<br/>(24V Pack)"]
    G --> I["Direct DC Loads<br/>(Sensors / LED / Fans)"]
    H --> J["Pure Sine Wave Inverter<br/>(230V AC 50Hz)"]
```

---

## Subsystem Functional Breakdown

### 1. Aerodynamic Harvesting Subsystem
- **Core Component**: Multi-propeller rotor cluster (tested in 3-rotor, 4-rotor, and 5-rotor configurations).
- **Aperture Diameter**: $300\text{ mm}$ ($0.3\text{ m}$) per single rotor unit; clustered effective swept footprint of $\approx 1.0\text{--}1.2\text{ m}$.
- **Airfoil Section**: Selig S1223 high-camber profile, specifically optimized for high lift coefficient ($C_L \approx 1.8\text{--}2.1$) in low Reynolds regimes ($Re < 100,000$).
- **Function**: Extracts momentum from low-speed airflow, converting stream dynamic pressure into rotational mechanical power at relatively low rotational speeds ($150\text{--}400\text{ RPM}$).

### 2. Mechanical Transmission Subsystem
- **Core Component**: Coaxial planetary gear system (spur configuration, module 2.5, $20^\circ$ pressure angle).
- **Gear Ratio**: 1:10 single-stage step-up (also evaluated with 3.77:1 intermediate ratio in scaled electrical models).
- **Arrangement**: Central sun gear driven by planetary cluster, coaxially coupled to minimize bending moments and radial bearing loads.
- **Function**: Steps up rotational speed by a factor of 10 to match the operating voltage-speed constant ($K_v$) of standard small DC generators, while trading off shaft torque and absorbing transmission frictional losses.

### 3. Electromechanical Conversion Subsystem
- **Core Component**: 100 W brushed/brushless DC generator.
- **Nominal Ratings**: $24\text{ V DC}$, rated current $4.16\text{ A}$ (with supplementary high-voltage tests conducted on $110\text{ V DC} / 3500\text{ RPM}$ motor-generators).
- **Conversion Efficiency**: $80\text{--}85\%$ at rated shaft angular velocity.
- **Function**: Converts high-speed mechanical shaft rotation into direct-current electrical output through electromagnetic induction.

### 4. Power Conditioning, Storage & Load Subsystem
- **Core Components**:
  - Schottky diode / bridge rectifier for bidirectional isolation.
  - Electronic Charge Controller with Battery Management System (BMS).
  - Energy Storage Pack: Nominal 24V DC battery bank (e.g., $24\text{ V}, 40\text{ Ah}$ lead-acid or LiFePO4).
  - Optional Pure Sine Wave Inverter: $24\text{ V DC} \rightarrow 230\text{ V AC}, 50\text{ Hz}$ for standard household appliances.
- **Function**: Stabilizes variable voltage generated under gusty wind conditions, protects battery from overcharge/deep discharge, and supplies power to DC or AC loads.

---

## Critical Engineering Trade-off: DC Bus Sizing (24V vs. 240V)

During the detailed electrical sizing of a 100 W micro-turbine, two architectural paths were calculated:

```
+-----------------------------------------------------------------------------------------+
|                               ELECTRICAL BUS SELECTION                                  |
+------------------------------------+----------------------------------------------------+
| High-Voltage DC Link (~240 V)      | Low-Voltage DC Bus (24 V / 48 V) [CHOSEN DESIGN]   |
+------------------------------------+----------------------------------------------------+
| - Stator power: ~77 W              | - Stator power: ~77 W                              |
| - Current: ~0.356 A                | - Current: ~3.2 A - 4.2 A                          |
| - Filter Inductor required: 127 mH | - Filter Inductor required: < 2.5 mH               |
| - High magnetic volume, bulky core | - Compact passive filtering, standard components   |
| - Difficult low-power switching    | - Readily available commercial charge controllers  |
| - Higher component dielectric cost | - Safe touch potential, ideal for rural homes      |
+------------------------------------+----------------------------------------------------+
```

As documented in the project calculation archives, attempting to step a 100 W generator directly to a high-voltage 240V DC link forces the electrical current down to fractions of an ampere ($I \approx 0.356\text{ A}$), requiring an impractically large filter inductor of **$127\text{ mH}$** and causing severe converter inefficiency. 

Therefore, the **24V DC bus** was selected as the baseline architecture for PAWAN SHAKTI, minimizing magnetic component mass, maximizing converter efficiency, and providing intrinsic electrical safety for residential rooftop deployment.

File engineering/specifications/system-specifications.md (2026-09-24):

# Engineering Specifications: PAWAN SHAKTI

## Baseline System Parameters (100 W Modular Architecture)

| Subsystem | Parameter | Specification / Nominal Value | Verification Basis |
| :--- | :--- | :--- | :--- |
| **System Envelope** | Height $\times$ Width $\times$ Depth | $1100\text{ mm} \times 950\text{ mm} \times 320\text{ mm}$ | Measured CAD assembly envelope |
| | Total System Dry Mass | $8.5\text{ kg}$ (chassis, rotors, gearbox, generator) | Measured scale weight |
| **Aerodynamics** | Rotor Configuration | Modular 4-Rotor Planar Matrix (Config B) | Prototyped & tested |
| | Single Rotor Diameter ($D$) | $300\text{ mm}$ ($0.3\text{ m}$) | CAD / Manufacturing spec |
| | Rotor Unit Radius ($R$) | $150\text{ mm}$ ($0.15\text{ m}$) | CAD specification |
| | Effective Total Swept Area | $0.283\text{ m}^2$ ($4 \times \pi \times 0.15^2$) | Mathematical calculation |
| | Blade Airfoil Profile | Selig S1223 high-lift low-Re profile | Profile coordinates (`S1223.dat`) |
| | Blade Count | 8 to 12 blades per rotor unit | Prototyped geometry |
| | Optimal Tip Speed Ratio ($\lambda_{\text{opt}}$)| $2.2\text{--}2.8$ | Aerodynamic calculation |
| **Transmission** | Gearbox Architecture | Coaxial Epicyclic / Planetary Gearbox | Prototyped & CAD modeled |
| | Speed Step-Up Ratio ($i$) | $1:10$ | Kinematic gear tooth count ratio |
| | Gear Tooth Module | Module 2.5 spur involute | CAD / 3D-print specification |
| | Pressure Angle | $20^\circ$ | Standard involute gear standard |
| | Transmission Efficiency ($\eta_{\text{gear}}$)| Estimated $80\text{--}88\%$ (polymer) | Analytical estimate (bench torque) |
| **Generator** | Generator Topology | Permanent Magnet DC Generator | COTS component datasheet |
| | Rated Continuous Power | $100\text{ W}$ | Manufacturer specification |
| | Nominal DC Bus Voltage | $24\text{ V DC}$ | Standard system architecture |
| | Rated Armature Current | $4.16\text{ A}$ | Calculated: $100\text{ W} / 24\text{ V}$ |
| | Rated Generator Shaft Speed | $3,000\text{--}3,500\text{ RPM}$ | Datasheet nominal rating |
| | Conversion Efficiency ($\eta_{\text{gen}}$)| $80\text{--}85\%$ at rated speed | Manufacturer specification |
| **Operational Limits**| Target Cut-In Wind Speed | $2.0\text{--}2.5\text{ m/s}$ | Observed empirical cut-in on bench |
| | Rated Wind Speed | $5.5\text{--}6.0\text{ m/s}$ | Aerodynamic target |
| | Survival / Cut-Off Wind Speed | $20.0\text{--}25.0\text{ m/s}$ (with furling) | Design target (requires storm test)|
| **Structural / Materials**| Rotor Blade Material | High-Impact ABS (FDM 3D printed) | Material specification |
| | Frame Chassis | 6063-T6 Extruded Aluminum Profiles | Fabrication specification |
| | Backplate & Flanges | 5052/6061 Aluminum Plate ($4\text{ mm}$) | CAD drawing specification |
| | Main Drive Shafts | C45 Precision Turned Ground Steel | Hardware specification |
| | Bearings | 608-2RS & 6000-2RS Deep Groove Ball | COTS specification |

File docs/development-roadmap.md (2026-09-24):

# Development Roadmap & Next Engineering Steps

This roadmap outlines the technical milestones required to transition PAWAN SHAKTI from an academic laboratory prototype into a robust, field-hardened distributed wind power system.

---

```
  Phase 1 (Months 1–3)        Phase 2 (Months 4–9)          Phase 3 (Months 10–18)
  Bench Calibration &         Extended Outdoor Field        Magnetic Gearing &
  Custom MPPT PCB Design      Trials & Durability Study     Pilot Demonstrations
         |                           |                             |
         v                           v                             v
  - Wind tunnel dynamometry   - 6-month rooftop deployment  - Contactless transmission
  - Coreless generator tests  - Cellular/LoRa telemetry     - Injection molding tooling
  - Machined Delrin gears     - Dynamic storm braking       - Off-grid pilot sites
```

---

## Phase 1: Near-Term Engineering Refinements (Months 1 – 3)

### 1. Precision Wind Tunnel Dynamometer Calibration
- **Objective**: Establish certified aerodynamic and electromechanical efficiency curves ($C_p\text{--}\lambda$ and $P\text{--}V_w$) across continuous flow velocities from $1.5\text{ to }10.0\text{ m/s}$.
- **Methodology**: Mount Mark-4 rotor cluster in the VNIT wind tunnel with an active torque transducer and calibrated optical encoder to measure mechanical torque before the generator.

### 2. Dedicated 24V Synchronous MPPT Charge Controller
- **Objective**: Replace passive diode rectification with an active synchronous buck-boost Maximum Power Point Tracking (MPPT) power electronic stage.
- **Specification**: Microcontroller-driven perturb-and-observe (P&O) algorithm tuned for rapid tracking during low-wind velocity ramps.

### 3. Precision Subtractive / Molded Gear Fabrication
- **Objective**: Eliminate FDM 3D-printing surface roughness and layer-cleavage failure modes in the transmission.
- **Specification**: CNC machine the sun and planet gears from Polyoxymethylene (POM / Delrin) and aerospace-grade 7075 Aluminum to minimize friction and tooth wear.

---

## Phase 2: Medium-Term Field Validation & Durability (Months 4 – 9)

### 1. Six-Month Continuous Rooftop Deployment
- **Objective**: Measure real-world energy harvest, weatherability, and reliability under natural diurnal wind variations on the VNIT Campus.
- **Monitoring**: Autonomous ESP32/LoRa logging platform recording wind speed, direction, ambient temperature, vibration, voltage, current, and accumulated watt-hours.

### 2. High-Wind Storm Survivability & Furling
- **Objective**: Validate overspeed protection mechanisms when wind velocity exceeds $15.0\text{ m/s}$.
- **Mechanism**: Implement passive aerodynamic furling (tail hinge deflection) combined with an active solid-state electronic dump load.

### 3. Environmental Degradation Analysis
- **Objective**: Evaluate polymer embrittlement, UV discoloration, bearing seal efficacy, and moisture ingress following seasonal monsoon exposure.

---

## Phase 3: Advanced Transmission & Pilot Scaling (Months 10 – 18)

### 1. Full Integration of Contactless Magnetic Gearing
- **Objective**: Build and benchmark a fully functional magnetic gear transmission based on [`engineering/cad/ringforferritemagnetsv2.f3d`](../engineering/cad/ringforferritemagnetsv2.f3d).
- **Goal**: Achieve zero-wear, zero-friction speed step-up to push cut-in velocity below $2.0\text{ m/s}$.

### 2. Off-Grid Pilot Demonstrations
- **Objective**: Deploy 3 to 5 pilot units at real-world inland field sites:
  - Rural medical clinic emergency lighting backup.
  - Remote weather / agricultural telemetry station.
  - Solar-wind hybrid microgrid installation.

### 3. Design for Manufacturing (DFM) & Cost Rationalization
- **Objective**: Transition from low-volume prototyping to mass-production tooling (injection-molded rotor blades and die-cast aluminum frame brackets), establishing verified bills of materials to achieve the ₹35,000 target unit cost.

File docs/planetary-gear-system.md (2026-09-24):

# Planetary Gear Transmission & Speed Step-Up System

## 1. Why a Mechanical Step-Up Transmission Was Considered

Small-scale wind rotors operating in low-speed airflows ($2.0\text{--}4.5\text{ m/s}$) naturally rotate at relatively low angular velocities ($150\text{--}350\text{ RPM}$) due to aerodynamic Tip Speed Ratio ($\lambda$) limits:

$$\omega_{\text{rotor}} = \frac{\lambda \cdot V_{\text{wind}}}{R}$$

For a rotor radius $R = 0.15\text{ m}$ at $V = 3.5\text{ m/s}$ and $\lambda = 2.5$:

$$\omega_{\text{rotor}} = \frac{2.5 \times 3.5}{0.15} \approx 58.3\text{ rad/s} \approx 557\text{ RPM}$$

However, standard low-cost direct-current (DC) generators require shaft speeds of **$1,500\text{ to }3,500\text{ RPM}$** to induce sufficient back-electromotive force ($E_b = k_e \cdot \omega$) to exceed typical battery charging thresholds ($12\text{ V}$ or $24\text{ V}$). 

Without speed multiplication, a direct-drive generator either produces negligible open-circuit voltage or requires an impractically large permanent-magnet machine with an excessive pole count, adding mass, cost, and high cogging torque.

---

## 2. Why Coaxial Planetary Gearing Was Selected

When stepping up speed between a wind rotor and a generator, several transmission architectures exist:

| Transmission Type | Alignment | Radial Load on Bearings | Power Density | Noise / Vibration | Suitability for PAWAN SHAKTI |
| :--- | :--- | :--- | :--- | :--- | :--- |
| **Single-Stage Parallel Spur** | Offset input/output | High cantilevered load | Low | Moderate | Asymmetric frame loading; awkward generator packaging. |
| **Timing Belt / Pulley** | Offset input/output | Constant radial belt tension | Medium | Low | Belt creep, environmental degradation (UV, rain), high pre-tension friction. |
| **Coaxial Planetary Gearbox** | **Fully in-line / coaxial** | **Self-centering; zero net radial load** | **Very High** | Low-Moderate | **Ideal for compact nacelle packaging, balanced bearing wear, and coaxial generator coupling.** |

### Advantages of Planetary (Epicyclic) Gearing:
1. **Coaxial Input and Output**: The rotor input shaft and generator output shaft share the exact same centerline axis, eliminating bending moments on the main chassis and reducing nacelle packaging volume.
2. **Radial Load Cancellation**: Planetary gears distribute tooth contact forces symmetrically across multiple planet gears (typically 3 or 4) around a central sun gear. The radial tooth separation forces cancel out, leaving nearly pure torsional loading on the central shaft bearings.
3. **High Torque Density**: Dividing torque across multiple meshing teeth reduces individual tooth root stresses, permitting compact additive-manufactured or molded gears.

---

## 3. Kinematic & Dynamic Relationships

```
              PLANETARY GEAR SPEED STEP-UP MECHANISM
                     
                        [ Ring Gear (Fixed or Input) ]
                                /        \
                        [Planet 1]      [Planet 2]
                                \        /
                            [ Sun Gear (Output) ]
                                    |
                            [ Planet Carrier ]
```

### Speed Ratio ($i$)
In the PAWAN SHAKTI step-up configuration, the rotor carrier drives the planet gears, which revolve inside a ring gear and drive the central sun gear at multiplied speed:

$$i = \frac{\omega_{\text{out}}}{\omega_{\text{in}}} = \frac{\omega_{\text{sun}}}{\omega_{\text{carrier}}} = 1 + \frac{Z_{\text{ring}}}{Z_{\text{sun}}}$$

Where:
- $Z_{\text{ring}}$ is the number of internal teeth on the ring gear.
- $Z_{\text{sun}}$ is the number of external teeth on the sun gear.
- Target Speed Step-Up Ratio: **$1:10$** (with an intermediate calculation baseline of **$3.77:1$** evaluated during preliminary electrical matching).

For an input rotor angular velocity $\omega_{\text{in}}$, the generator shaft speed is:

$$\omega_{\text{gen}} = i \cdot \omega_{\text{rotor}} = 10 \cdot \omega_{\text{rotor}}$$

---

## 4. Fundamental Torque-Speed Trade-Off & Mechanical Losses

A mechanical gearbox **does not create energy**. By the principle of conservation of energy:

$$P_{\text{mech, out}} = P_{\text{mech, in}} \cdot \eta_{\text{gearbox}}$$

Where $\eta_{\text{gearbox}} < 1.0$ is the mechanical transmission efficiency.

The output torque ($T_{\text{out}}$) delivered to the generator shaft is therefore reduced inversely with speed, diminished further by mechanical friction:

$$T_{\text{gen}} = \frac{T_{\text{rotor}}}{i} \cdot \eta_{\text{gearbox}} = \frac{T_{\text{rotor}}}{10} \cdot \eta_{\text{gearbox}}$$

### Sources of Mechanical Losses in the Prototype:
1. **Sliding & Rolling Tooth Friction**: Meshing between gear teeth involves micro-sliding along the involute flank ($20^\circ$ pressure angle). In FDM-printed ABS gears, surface roughness ($R_a \approx 10\text{--}25\text{ }\mu\text{m}$) increases tooth friction compared to precision ground metal gears.
2. **Bearing Drag**: Rolling resistance from deep-groove ball bearings and contact seal drag.
3. **Windage & Churning**: Fluid drag of rotating gear components in air or lubricant.

```
       Input Aerodynamic Power (Rotor)
       P_in = T_rotor * omega_rotor
                |
                v  [ Frictional Dissipation: ~10 - 20% in polymer prototype ]
                |
       Output Mechanical Power (Generator Shaft)
       P_out = T_gen * omega_gen = eta_gearbox * P_in
```

Under low-wind conditions, transmission frictional torque directly opposes starting torque. Reducing gearbox tare friction is therefore paramount to ensuring low cut-in operation.

---

## 5. Experimental Magnetic Gear Coupling Exploration

To eliminate contact friction, tooth wear, and lubrication maintenance altogether, preliminary research was conducted into **contactless magnetic gear couplings**:
- **Design Asset**: [`engineering/cad/ringforferritemagnetsv2.f3d`](../engineering/cad/ringforferritemagnetsv2.f3d) and [`ringforferritemagnetsv2.stl`](../engineering/cad/stl-and-3mf/ringforferritemagnetsv2.stl).
- **Concept**: Ferrite / Neodymium permanent magnets arranged with alternating polarity on concentric rings, modulated by intermediate ferromagnetic pole pieces.
- **Benefits**: Zero contact friction, natural overload slip protection without tooth stripping, zero acoustic meshing noise.
- **Current Status**: Exploratory research and initial 3D-printed fixture design; full dynamometer characterization remains future work.

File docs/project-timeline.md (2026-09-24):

# Project Development Timeline

This factual timeline chronicles the documented engineering development, intellectual property, testing milestones, and institutional backing of the PAWAN SHAKTI initiative.

---

```
  2023 - 2024          Early 2025            May 2025          July - Aug 2026      Sept 2026+
  Conceptual &       Mark-3 Prototype       Fusion 360 CAD     ESP32 Sensor Test   VNIT Pre-Incubation
  Aerodynamic R&D    & Planetary Gear      Formal Drawings     Runs (Configs A,B)  & Magnetic Gear R&D
       o-------------------o--------------------o----------------------o-------------------o
```

---

## Chronological Milestones

### 2023 – 2024: Problem Identification & Preliminary Modeling
- **Milestone**: Identification of low-wind-speed limitations for inland Indian micro-power applications.
- **Engineering Activity**: Initial aerodynamic study on low-Reynolds-number airfoils; identification of the Selig S1223 high-camber profile.
- **Evidence / Output**: Selig airfoil coordinate database integration ([`engineering/airfoil/S1223.dat`](../engineering/airfoil/S1223.dat)) and preliminary Betz limit scaling derivations.

### Early 2025: Mark-3 Prototype & Patent Publication
- **Milestone**: Fabrication of the first integrated multi-rotor prototype (Mark-3, 3-rotor layout).
- **Engineering Activity**: 3D printing of ABS rotor impellers with integrated module 2.5 gear teeth; coaxial planetary gearbox integration with DC generator.
- **Intellectual Property**: Publication of Indian Patent: *"Compact Wind Turbine with Planetary Gears"* (2025).
- **Evidence / Output**: Physical prototype photographs ([`media/prototype/mark-3-three-rotor-prototype.png`](../media/prototype/mark-3-three-rotor-prototype.png)).

### May 2025: Formal CAD Assemblies & Engineering Drawings
- **Milestone**: Comprehensive CAD mechanical modeling in Autodesk Fusion 360.
- **Engineering Activity**: Full assembly modeling, backplate machining drawings, structural extrusion framing, and gear tooth profile verification.
- **Evidence / Output**: Formal 2D Engineering Drawings issued on **18 May 2025** ([`engineering/drawings/drawings1.pdf`](../engineering/drawings/drawings1.pdf) and [`engineering/drawings/drawings-2.pdf`](../engineering/drawings/drawings-2.pdf)).

### Late 2025 – Early 2026: Multi-Rotor Matrix Evaluation (Mark-4 & Mark-5)
- **Milestone**: Development and bench evaluation of 4-rotor (Mark-4) and 5-rotor (Mark-5 / Project KECS) prototypes.
- **Engineering Activity**: Investigation of power combining from multiple rotors; flow channel evaluations in VNIT aerodynamics facilities.
- **Evidence / Output**: Physical test rig photographs ([`media/prototype/mark-4-four-rotor-prototype.png`](../media/prototype/mark-4-four-rotor-prototype.png) and [`media/prototype/mark-5-five-rotor-kecs-prototype.jpg`](../media/prototype/mark-5-five-rotor-kecs-prototype.jpg)).

### July – August 2026: Sensor Instrumentation & Testing Protocols
- **Milestone**: Implementation of ESP32 automated multi-sensor datalogging architecture.
- **Engineering Activity**: Integration of cup anemometer, optical tachometers, voltage/current ADCs, and vibration sensors; establishment of comparative rotation test protocols across Configurations A, B, and C.
- **Evidence / Output**: Intern Task Brief documented on **29 July 2026** ([`testing/test-protocols/ESP32-Sensor-Logging-Protocol.md`](../testing/test-protocols/ESP32-Sensor-Logging-Protocol.md)).

### September 2026: Pre-Incubation Agreement & Institutional Expansion
- **Milestone**: Formal institutional backing and incubation approval.
- **Institutional Milestone**: Execution of Pre-Incubation Agreement with **VNIT Ventures Vault Foundation (V3F)**, VNIT Nagpur (Effective Date: **21 September 2026**; signed **23 September 2026**).
- **Research Expansion**: Support acknowledged under ANRF accelerated research grant schemes; exploratory development of magnetic contactless gearing.
- **Evidence / Output**: Pre-incubation records ([`reports/VNIT-Pre-Incubation-Agreement-Summary.md`](../reports/VNIT-Pre-Incubation-Agreement-Summary.md)) and magnetic gear CAD models ([`engineering/cad/ringforferritemagnetsv2.f3d`](../engineering/cad/ringforferritemagnetsv2.f3d)).

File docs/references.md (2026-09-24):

# References & Academic Citations

This document organizes the foundational literature, design standards, datasheets, and academic contributions underpinning the PAWAN SHAKTI research initiative.

---

## 1. Project Research & Affiliated Publications

1. **Yaswanth, K., & Bhukya, J.** (2025). *"Affordable Low-Wind Rooftop Wind Turbine Energy System Design for Rural Electrification."* Department of Electrical and Electronics Engineering, Visvesvaraya National Institute of Technology (VNIT), Nagpur.
2. **Yaswanth, K., & Bhukya, J.** (2025). *"A Space-Efficient Multi-Rotor Wind Turbine System for Decentralized Power."* VNIT Nagpur.
3. **Yaswanth, K.** (2025). *"Compact Wind Turbine with Planetary Gears."* Indian Patent Application / Publication (Published 2025).

---

## 2. Foundational Wind Energy & Aerodynamic Literature

1. **Betz, A.** (1920). *"Das Maximum der theoretisch möglichen Ausnützung des Windes durch Windmotoren."* *Zeitschrift für das gesamte Turbinenwesen*, 26, 307–309. (Derivation of the theoretical maximum power coefficient $C_{p,\max} = \frac{16}{27} \approx 0.593$).
2. **Selig, M. S., & Guglielmo, J. J.** (1997). *"High-Lift Low Reynolds Number Airfoil Design."* *Journal of Aircraft*, 34(1), 72–79. DOI: 10.2514/2.2137. (Aerodynamic rationale and polar data for Selig S1223 high-camber profile).
3. **Wu, B., Lang, Y., Zargari, N., & Kouro, S.** (2011). *Power Conversion and Control of Wind Energy Systems.* IEEE Press / John Wiley & Sons. ISBN: 978-0-470-59365-3. (Reference textbook preserved in repository archives: wind generator topologies, DFIG converter sizing, and pitch/torque control dynamics).
4. **Manwell, J. F., McGowan, J. G., & Rogers, A. L.** (2010). *Wind Energy Explained: Theory, Design and Application.* (2nd ed.). John Wiley & Sons.
5. **Burton, T., Jenkins, N., Sharpe, D., & Bossanyi, E.** (2011). *Wind Energy Handbook.* (2nd ed.). John Wiley & Sons.

---

## 3. Power Systems & Grid Interconnection References

1. **Lin, B., & Okoye, J. O.** (2023). *"Towards renewable energy generation and low greenhouse gas emission in high-income countries: Performance of financial development and governance."* *Renewable Energy*, 215, 118931. DOI: 10.1016/j.renene.2023.118931.
2. **Zhong, Z., Hu, W., & Zhao, X.** (2024). *"Rethinking electric vehicle smart charging and greenhouse gas emissions: Renewable energy growth, fuel switching, and efficiency improvement."* *Applied Energy*, 361, 122904. DOI: 10.1016/j.apenergy.2024.122904.
3. **Eladl, A. A., et al.** (2024). *"A comprehensive review on wind power spillage: Reasons, minimization techniques, real applications, challenges, and future trends."* *Electric Power Systems Research*, 226, 109915. DOI: 10.1016/j.epsr.2024.109915.
4. **Qazi, A., et al.** (2019). *"Towards Sustainable Energy: A Systematic Review of Renewable Energy Sources, Technologies, and Public Opinions."* *IEEE Access*, 7, 63837–63851. DOI: 10.1109/ACCESS.2019.2906402.

---

## 4. International & National Standards

1. **IEC 61400-2**: *Wind energy generation systems – Part 2: Small wind turbines.* International Electrotechnical Commission. (Specifies structural safety, aerodynamic design requirements, mechanical load cases, and test procedures for small turbines with swept area $\le 200\text{ m}^2$).
2. **IEC 61400-12-1**: *Wind turbines – Part 12-1: Power performance measurements of electricity producing wind turbines.* International Electrotechnical Commission. (Methodology for anemometer placement, binning, and power curve calibration).
3. **IS 12383 / Bureau of Indian Standards (BIS)**: *Code of practice for design and installation of wind pumping and power systems.*

---

## 5. Manufacturer Specifications & Hardware Datasheets

1. **100 W Permanent Magnet DC Generator Datasheet**: Rated voltage $24\text{ V DC}$, rated speed $3,000\text{ RPM}$, rated current $4.16\text{ A}$, conversion efficiency $80\text{--}85\%$.
2. **Espressif Systems ESP32-WROOM-32D Datasheet**: 32-bit dual-core Xtensa MCU, 12-bit SAR ADC, hardware timers for pulse-counting interrupt acquisition.
3. **Allegro MicroSystems ACS712 Datasheet**: Fully integrated, Hall-effect-based linear current sensor IC.

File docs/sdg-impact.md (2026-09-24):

# United Nations Sustainable Development Goals (SDGs) Alignment

The PAWAN SHAKTI engineering research initiative explores technological pathways toward decentralized, low-carbon power generation. The project aligns with three specific United Nations Sustainable Development Goals (SDGs), focusing on practical engineering contributions rather than claiming instantaneous global solutions.

---

## SDG 7: Affordable and Clean Energy

> **Target 7.1 & 7.2**: Ensure universal access to affordable, reliable, and modern energy services; increase substantially the share of renewable energy in the global energy mix.

### How PAWAN SHAKTI Aligns & Contributes:
- **Expanding Renewable Harvesting Boundaries**: Over $70\%$ of the world's populated landmass experiences average surface wind velocities below $5.0\text{ m/s}$. Conventional small-wind technologies operate effectively only in coastal or high-elevation corridors, leaving inland populations reliant exclusively on fossil generators or intermittent solar. Investigating micro-turbines with cut-in speeds between $2.0\text{ and }2.5\text{ m/s}$ **supports exploration of** viable renewable generation across inland rural communities.
- **Solar-Wind Complementarity**: Solar PV is inherently constrained to daylight hours. By exploring micro-wind energy harvesting that functions during evening and nighttime convective breeze periods, PAWAN SHAKTI **contributes toward** reducing the battery storage capacity required for continuous off-grid rural power systems.
- **Affordable Modular Hardware**: Investigating low-cost materials (thermopolymers, commercial modular extrusions, and accessible manufacturing methods) **aims to lower** the capital cost barrier for decentralized energy hardware.

---

## SDG 9: Industry, Innovation, and Infrastructure

> **Target 9.4 & 9.5**: Upgrade infrastructure and retrofit industries to make them sustainable; enhance scientific research and upgrade technological capabilities.

### How PAWAN SHAKTI Aligns & Contributes:
- **Decentralized Infrastructure Resilience**: Powering distributed micro-infrastructure—such as remote environmental monitoring stations, rural telecommunication relays, and agricultural telemetry—frequently relies on expensive grid extensions or diesel generators. PAWAN SHAKTI **investigates compact renewable infrastructure** capable of operating as an auxiliary power unit in low-wind conditions.
- **Academic & Applied Engineering Research**: Conducted within the research ecosystem of VNIT Nagpur and supported by ANRF grant frameworks and the VNIT Ventures Vault Foundation (V3F), the project **supports student and institutional R&D capacity** in mechanical design, additive manufacturing, and renewable power systems.
- **Local Manufacturability**: By utilizing standardized components, desktop 3D printing, and modular chassis framing, the system **explores decentralized production models** where small-scale hardware can be assembled and maintained by local technicians without specialized overseas supply chains.

---

## SDG 13: Climate Action

> **Target 13.2**: Integrate climate change measures into national policies, strategies, and planning.

### How PAWAN SHAKTI Aligns & Contributes:
- **Displacement of Fossil Fuel Backup**: In off-grid and weak-grid environments, nighttime power shortages are overwhelmingly met with small diesel and kerosene generators, which emit significant carbon dioxide ($CO_2$), nitrogen oxides ($NO_x$), and unburned particulate matter. A functional 100 W micro-wind system operating at modest capacity factor **contributes to offsetting** fuel consumption in low-power baseline applications.
- **Low-Carbon Lifecycle Investigation**: By evaluating recyclable polymers (ABS/PETG), mechanical longevity through magnetic gear couplings, and modular component replacement, the research **supports exploration of** sustainable lifecycle engineering for distributed renewable hardware.

---

## Evidentiary Boundaries & Honest Framing

To maintain academic and professional integrity:
- PAWAN SHAKTI **does not claim** to have eliminated energy poverty or replaced utility power grids.
- The project **is an early-stage prototype and experimental research program** evaluating the technical limits and trade-offs of micro-wind harvesting in low-velocity wind regimes.
- Its ultimate societal impact depends entirely upon completing structured multi-season field validation, proving mechanical durability, and establishing repeatable manufacturing economics.

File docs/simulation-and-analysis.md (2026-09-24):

# Simulation & Numerical Analysis

## Engineering Principle: Simulation $\neq$ Physical Test

> [!IMPORTANT]
> Numerical simulations (FEA and computational modeling) provide critical design guidance, stress identification, and qualitative behavioral trends. However, **simulations are not physical validations**. Real-world performance includes fluid turbulence, boundary-layer transitions, manufacturing surface roughness, backlash, and electromechanical losses that idealized numerical models cannot fully capture.

---

## 1. Simulation Objectives

Finite Element Analysis (FEA) and aerodynamic modeling were conducted in ANSYS and Fusion 360 Simulation with three primary objectives:
1. **Structural Integrity Evaluation**: Verify that additive-manufactured ABS rotor blades and gear teeth withstand maximum operating aerodynamic thrust and centrifugal loads without exceeding material yield limits.
2. **Deflection & Clearance Verification**: Assess blade tip deflection under aerodynamic drag forces to ensure blades do not deflect into the frame or adjacent rotors.
3. **Stress Concentration Identification**: Locate peak von Mises stress zones at the blade root fillets, gear tooth roots, and shaft hub junctions to optimize fillet radii and print infill density.

---

## 2. Computational Setup & Boundary Conditions

### A. Material Assumptions
Simulations modeled isotropic and orthotropic properties corresponding to 3D-printed Acrylonitrile Butadiene Styrene (ABS) and structural 6061-T6 Aluminum:

| Property | 3D-Printed ABS (As-Built FDM) | 6061-T6 Aluminum (Frame / Backplate) |
| :--- | :--- | :--- |
| **Density ($\rho$)** | $1,040\text{ kg/m}^3$ | $2,700\text{ kg/m}^3$ |
| **Young's Modulus ($E$)** | $1.8\text{--}2.2\text{ GPa}$ (directionally dependent) | $68.9\text{ GPa}$ |
| **Poisson's Ratio ($\nu$)** | $0.35$ | $0.33$ |
| **Tensile Yield Strength ($\sigma_y$)** | $28\text{--}35\text{ MPa}$ (inter-layer limit: $\approx 20\text{ MPa}$) | $276\text{ MPa}$ |
| **Ultimate Tensile Strength ($\sigma_u$)**| $35\text{--}42\text{ MPa}$ | $310\text{ MPa}$ |

### B. Geometry & Meshing
- **Blade Geometry**: Selig S1223 airfoil section extruded with variable chord and twist distribution along the span ($R = 150\text{ mm}$).
- **Mesh Type**: Unstructured tetrahedral elements with localized prism boundary layer refinement along blade root fillets and gear tooth roots.
- **Mesh Sensitivity**: Verified by comparing peak stress between coarse ($1.5\text{ mm}$ element size) and refined ($0.4\text{ mm}$ fillet refinement) meshes until stress convergence within $5\%$ was achieved.

### C. Boundary Conditions & Applied Loads
1. **Fixed Constraints**: The central shaft bore and mounting hub faces were fully constrained in all degrees of freedom ($u_x = u_y = u_z = 0$).
2. **Centrifugal Load**: Rotational velocity applied about the central axis up to extreme overspeed conditions ($\omega_{\max} = 1,200\text{ RPM} \approx 125.7\text{ rad/s}$).
3. **Aerodynamic Thrust & Torque**: Pressure distribution mapped over the blade surface representing extreme aerodynamic load at $V = 15\text{ m/s}$ ($P_{\text{dyn}} \approx 130\text{ Pa}$).

---

## 3. Results vs. Interpretation

```
+-----------------------------------------------------------------------------------------+
| NUMERICAL SIMULATION RESULT (FEA)       | ENGINEERING INTERPRETATION                    |
+-----------------------------------------+-----------------------------------------------+
| - Peak von Mises stress: 8.2 MPa        | - Factor of safety (FoS) > 2.4 relative to    |
|   located at the root trailing-edge     |   layer bonding limit (~20 MPa).              |
|   fillet during maximum overspeed.      | - Root fillet radius was enlarged from 1.5mm  |
|                                         |   to 3.0mm to mitigate stress concentration.  |
|                                         |                                               |
| - Maximum blade tip displacement:       | - Deflection is well within the 25 mm axial   |
|   1.8 mm in the axial downstream        |   clearance between the rotor plane and the   |
|   direction at 12 m/s equivalent drag.  |   support extrusion frame. No collision risk. |
|                                         |                                               |
| - Gear tooth bending stress at root:    | - Module 2.5 spur tooth geometry is adequate  |
|   11.4 MPa under rated torque transfer. |   for steady loads, but cyclic fatigue and    |
|                                         |   impact shock require metal or nylon pinion. |
+-----------------------------------------+-----------------------------------------------+
```

---

## 4. Modeling Limitations & Boundary-to-Reality Gaps

1. **Anisotropy of Additive Manufacturing**: Standard FEA treats the material as isotropic. FDM 3D-printed parts exhibit lower tensile strength along the Z-axis (inter-layer cleavage) than along the X-Y print plane. Print orientation was specifically oriented along the blade span to ensure continuous filament lines carry tensile bending loads.
2. **Unsteady Aerodynamics**: Static pressure mapping does not account for turbulent wind gusts, wake shedding, dynamic stall, or cross-rotor aerodynamic interference between adjacent propellers in the multi-rotor array.
3. **Thermal & Creep Effects**: Polymer gear teeth experience frictional heating at high rotational speeds, which can cause localized thermal softening not accounted for in linear elastic simulations.

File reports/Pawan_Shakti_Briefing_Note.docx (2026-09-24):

PAWAN SHAKTI

Decentralized Wind Energy for the Inland World — Technical & Business Briefing Note

Pawan Shakti is developing a compact, low-cost small-scale wind turbine (SSWT) system engineered specifically for the low-wind conditions typical of inland India — where conventional wind and solar technologies are unreliable or unavailable. The system pairs CFD-optimized multi-propeller blades with a compact planetary gearbox to generate usable power at wind speeds as low as 1.5–3.5 m/s, well below the 5 m/s+ threshold required by conventional small-wind systems.

Mission: “Apna ghar, apna turbine.”

Founder: Yaswanth

Incubator: VNIT Venture Vault Foundation (V3F)

Academic Mentor: Dr. J. Bhukya

The Problem & Our Differentiation

Conventional small-wind systems require wind speeds above 5.0 m/s to begin generating power, leaving most inland Indian sites — where average wind speeds are far lower — unserved by wind energy. Solar alone is intermittent, and existing small-wind hardware is bulky, complex, and expensive to install.

Vector | Conventional Small-Wind | Pawan Shakti
Cut-in wind speed | > 5.0 m/s required | Efficient at 1.5–3.5 m/s (micro-wind ready)
Availability | Highly intermittent (solar/wind) | Maximum active time; bypasses solar gaps
Footprint | Bulky, industrial, unfit for rooftops | Compact, simple local assembly
Unit cost | Prohibitively high | ~₹35,000 for mass deployment

Hero Product: 100W Modular Wind System

A 100 W modular SSWT explicitly optimized for wind speeds under 5 m/s, combining:

- CFD-designed multi-propeller blades for enhanced aerodynamic efficiency at low wind speeds
- A compact planetary gearbox-generator system (pressure angle –20°) for speed and torque enhancement
- A DC generator rated 110 V DC, 3500 RPM, 100 W per unit, feeding a pure sine-wave DC-to-AC inverter (230 V AC, 50 Hz) via a 12 V, 100 Ah battery
- Cut-in speed 2.3–2.5 m/s, cut-off speed 25 m/s — powering mobile charging, LED/CFL lighting, fans, small agricultural water pumps, and other domestic/agricultural loads

The system has progressed through Mark-3, Mark-4, and Mark-5 prototypes, with three- and four-propeller 100 W configurations validated in wind tunnel testing at VNIT Nagpur, and is supported by two academic papers: “Affordable Low-Wind Rooftop Wind Turbine Energy System Design for Rural Electrification” and “A Space-Efficient Multi-Rotor Wind Turbine System for Decentralized Power.”

IP & Strategic Backing

- Published patent: “Compact Wind Turbine with Planetary Gears” (2025); active filing in progress for turbine and magnetic gear integration
- Supported by ANRF accelerated research grants and the CBDE R&D scheme
- Incubated by VNIT Venture Vault Foundation (V3F)

Where This Fits

Pawan Shakti is positioned as a complement to rooftop solar rather than a replacement — providing decentralized, reliable power that offsets solar's intermittency for rural households, small farms, micro-grids, telecom towers, and remote monitoring stations. It targets segments across residential rooftops, rural schools & clinics, and disaster-relief backup power.

Our Aim

Our goal is to take Pawan Shakti beyond a validated lab prototype and build it into a real, industry-grade product — one that is manufacturable at scale, reliable in the field, and ready for wider deployment. This means strengthening the engineering (blade aerodynamics, gearbox and generator design, power electronics), running structured field trials to prove durability and energy yield under real-world conditions, and setting up a repeatable local-assembly and manufacturing process.

Beyond the turbine itself, this project is central to growing the startup as a whole — building out the team, formalizing our IP position, and establishing the partnerships and manufacturing know-how needed to move from a university project to a functioning company.

Core Team

Yaswanth (Founder & Lead) drives strategy, vision, and commercialization, with Dr. J. Bhukya as Academic Mentor providing strategic oversight and research guidance. The engineering team covers CAD & modeling, blade design (CFD/aerodynamics), electronics (embedded systems & PCB), system integration, generator R&D, power electronics, prototyping/workshop operations, and field deployment logistics.

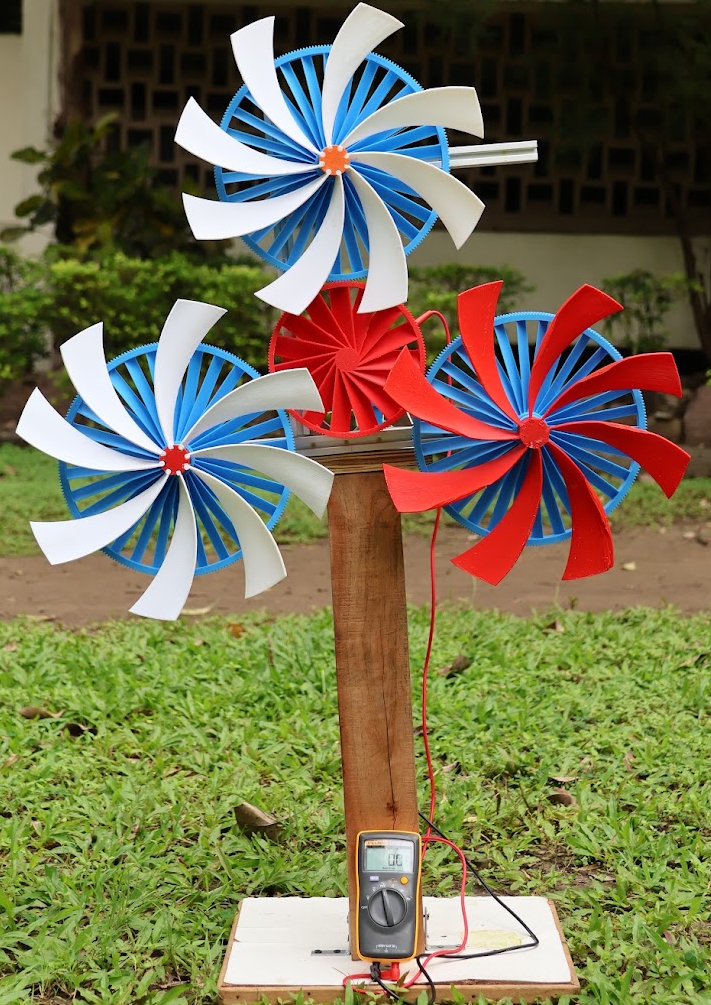
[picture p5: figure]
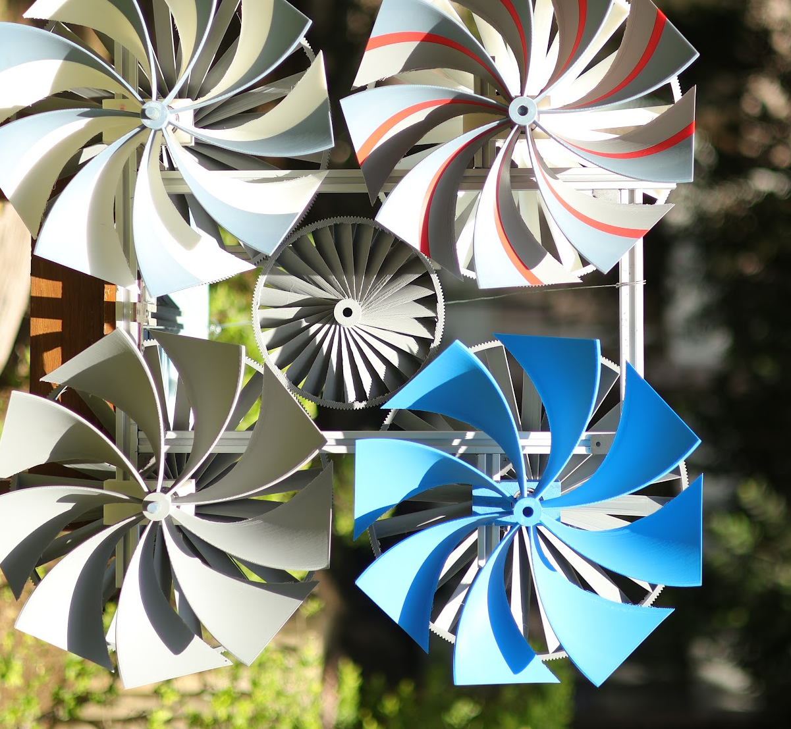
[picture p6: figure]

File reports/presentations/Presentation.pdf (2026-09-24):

## FORECAST

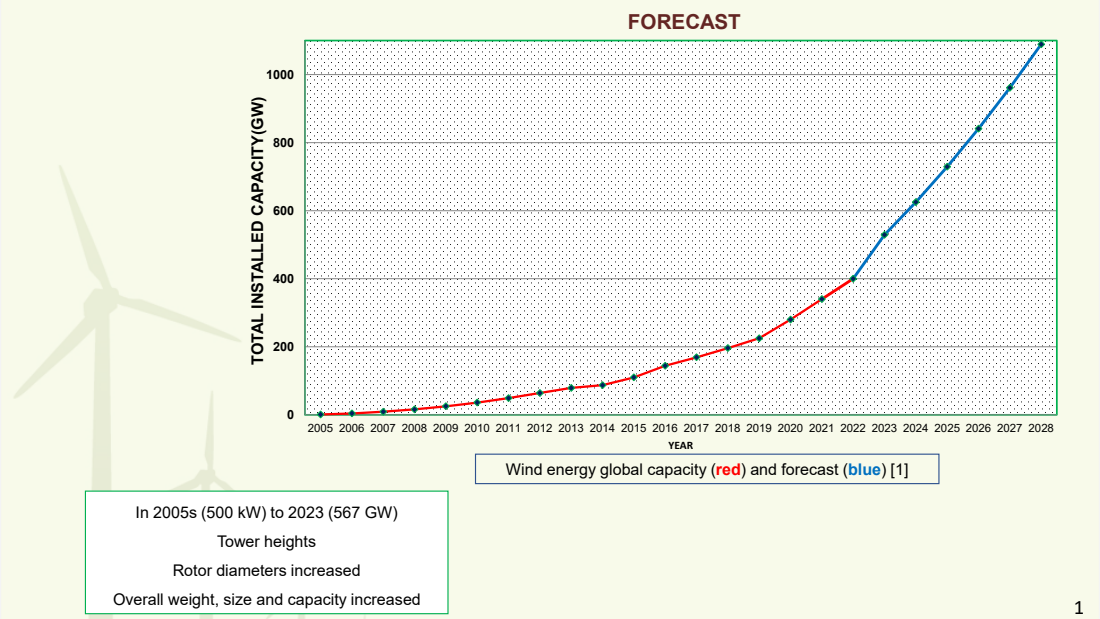
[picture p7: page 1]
2005 2006 2007 2008 2009 2010 2011 2012 2013 2014 2015 2016 2017 2018 2019 2020 2021 2022 2023 2024 2025 2026 2027 2028 YEAR; Tower heights

TOTAL INSTALLED CAPACITY(GW)

Wind energy global capacity (red) and forecast (blue) [1]

Rotor diameters increased

Overall weight, size and capacity increased

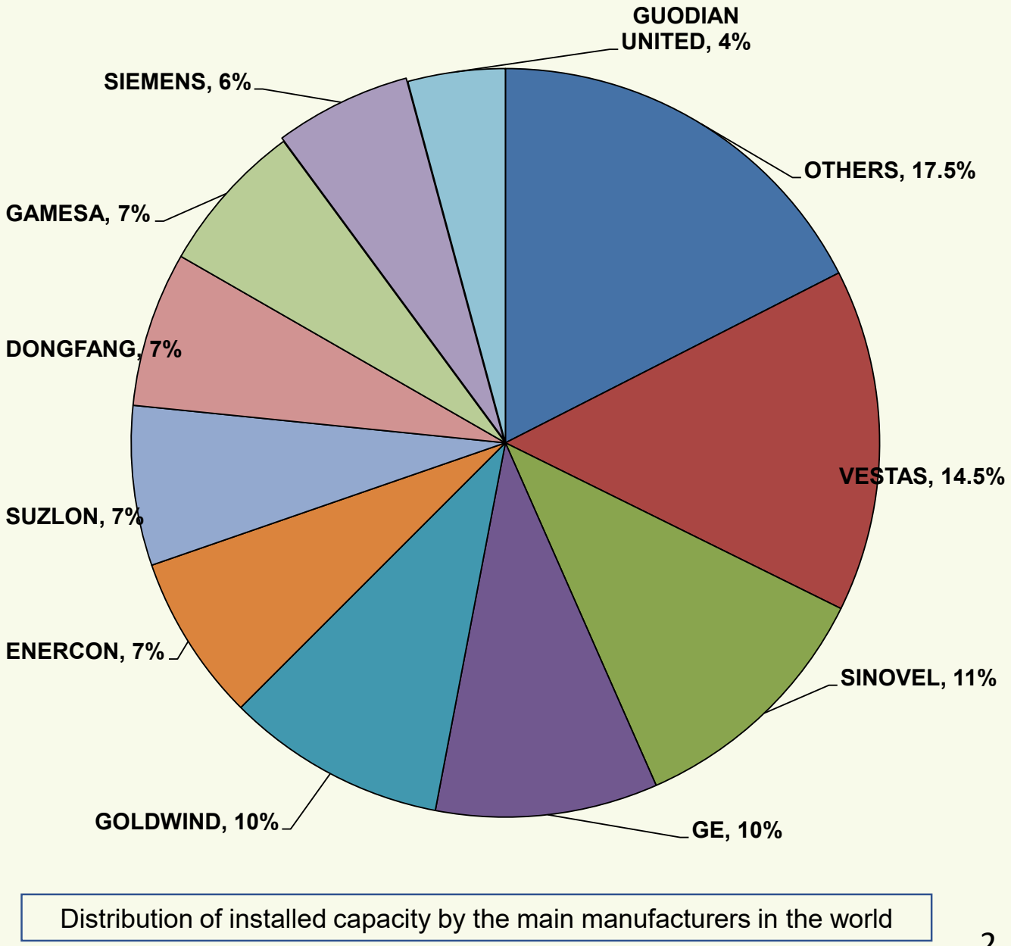
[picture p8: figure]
OTHERS, 17.5%; VESTAS, 14.5%; SINOVEL, 11%; GOLDWIND, 10%; ENERCON, 7%; SUZLON, 7%; DONGFANG, 7%; GAMESA, 7%; SIEMENS, 6%; GUODIAN UNITED, 4%

Distribution of installed capacity by the main manufacturers in the world

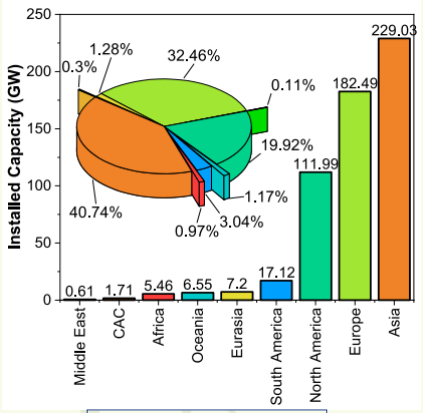
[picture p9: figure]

Regional installed wind capacity

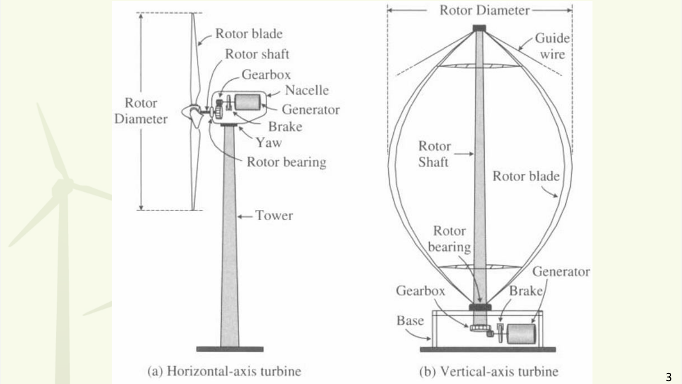
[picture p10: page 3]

110

DFIG | SYNCHRONOUS GENERATOR | 2 BLADES

Power system grid with wind integration | 7

Wind energy conversion form mechanical to electrical

Power Electronic Converter (PEC)

# Types of Wind Turbine Generators (WTGs)

## The main generators configurations used in WTs are

## (A) Squirrel Cage Induction Generator (SCIG)

## (B) Wound Rotor Induction Generator (WRIG)

## (C) Permanent Magnet Synchronous Generator (PMSG)

or

## Electrically Excited Synchronous Generator (EESG)

or

## Direct-driven Permanent Magnet Wind Power Generators (DDPMG)

## (D) Doubly Fed Induction Generator (DFIG)

(A). Squirrel Cage Induction Generator (SCIG)

Type A and B System:

• Induction generator (squirrel cage (type A)

Constant speed wind power generation system with SCIG

and wound rotor (type B))

(B). Wound Rotor Induction Generator (WRIG)

• Capacitors (Provide Reactive power to

induction generator and to the grid (very limited))

• Gearbox to boost shaft speed (nearly 100

• Slip rings for type B.

• Control resistor for type B.

Introduces additional heat dissipation

Variable speed wind power generation system with WRIG

## (C). Permanent Magnet Synchronous Generator (PMSG)

Variable speed wind power generation system with PMSG (fully-rated PEC)

## Type C System:

- Generator (asynchronous, permanent magnet) or synchronous.
- AC/DC generator side converter (covert AC (different frequency) to DC)
- DC/AC grid side converter convert DC to AC (50 Hz / 60 Hz as needed).
- Gearbox (eliminated in direct drive).

- The DFIG is essentially a wound rotor induction generator in which

the rotor circuit can be controlled by external devices to achieve

variable speed operation.

- Leading and lagging reactive power

## (D). Doubly Fed Induction Generator (DFIG)

## Type D System:

- Induction generator (wound rotor), double-fed (DFIG).
- Gearbox to boost shaft speed (nearly 100 times).
- AC/DC-DC/AC converter (provide second supply to the

wound rotor)

- Crowbar to protect rotor winding throughout the faults.

DFIG based WTG integrated with the grid

(i) super synchronous speed (ωs > ωr

(ii) sub synchronous speed (ωs < ωr

Power flow directions in DFIG of WTGs.

YEAR | DIAMETER (METER) | POWER GENERATION | POWER ELECTRONIC CONVERSION
1990 | 15 m | 50 KW | Rating is 0%, and Operational role is Soft starter (A Type)
1995 | 20 m | 100 KW
2000 | 40 m | 500 KW
2000 | 50 m | 600 KW | Rating is 10%, and Operational role Rotor
| 80 m | 2 MW | resistance control (B Type) 2005
2010 - 2025 | 124 m | 5 MW | Rating is 30%, and Operational role is the Rotor power control (C Type)
2015 - 2025 | 164 m | 7-7.5 MW | Rating is100% and Operational role is Full generator power control (D Type)
| 210 m | 10 MW

Wind turbine evolution and the main trend of power electronic conversion in the last 35 years

Generator Concept (Type) | SCIG (A) | WRIG (B) | PMSG(C) | DFIG (D)
Type of speed | Fixed/constant speed wind turbine | Limited variable speed wind turbine | Variable speed wind turbine | Variable speed wind turbine
Gearbox stages | 3 | 3 | None | 3
Control | Active stall, Passive stall Pitch | Pitch | Pitch | Pitch
Individual speed control | Yes | No | No | Yes
Power output of the system control by | Soft starter | Rotor resistance control | Full generator power control | Rotor power control
Energy produced | Less | Moderate-high | High | Moderate-high
Standby function | Yes | No | Yes | Yes
Reliability | Very high | High | High | Moderate
Technical growth | High | High | Medium- high | High
Electric grid support for stability | Low | High | High | Medium
Power ratings (kW) And Rotor Diameter (m) | (270, 27)/ (300, 28)/ (600, 43)/ (800, 49)/ (1000, 54)/ (1320, 61)/ (2300, 82.4). | (600, 39)/ (660, 47)/ (1800, 80)/ (2100, 88). | (600, 40)/ (1500, 70)/ (2500, 90)/ (3000, 101)/ (3600, 107)/ (4100, 113)/ (4500, 114) | (1500,70.4/77/82)/ (1800, 90)/ (2500, 90)/ (2250, 88)/ (2750, 80)/ (2000, 90/92.5)/ (3000, 90/91.6

## Summary of Wind Energy Conversion Systems

Cost | Less | High | Medium-high | Medium
Maintenance | Medium | High | Medium | Medium
Reactive power control | • Capacitor banks • SVCs or SATCOM •No frequency control | • Fully scale frequency/ Power converter | • Fully scale frequency/ Power converter | •Partially/fully scale frequency/power converter (25-30%) • For some special case extra protection required for a crowbar
Advantages | •Easier to design, construct and control • Robust operation | • High energy yield • Higher active/reactive Power controllability • Absence of brush/slip ring • Low mechanical stress | • Highest energy yield • Higher active/reactive Power controllability • Absence of brush/slip ring • Low mechanical stress • No copper losses on the rotor | • High energy yield •High active/reactive power Controllability • Lower cost on PEC • Lower losses by PEC • Less mechanical stress • Compact size
Disadvantage | • Low energy yield •No active/reactive power controllability • High mechanical stress • High losses on gear | • Higher cost of copper winding • Higher cost on PEC • Higher losses on PEC • Large size | • High cost of PM material • Demagnetization of PM •Complex construction process • Higher cost on PEC • Higher losses on PEC • Large size | •Existence of brush/slip ring • High losses on gear
Major manufacturing companies | Vestas (V27), Siemens (B54, B82), Neg Micon (M530, M1500), Tacke (TW600), Made (AE-61), Nordex (N52), | Vestas (39,44,47), Suzlon(S88), Gamesa (G80). | GE (GE 4,1-113), Goldwind (GW70,90), Enercon (E-40,66,112, 126), Dongfang (DF82-1500), Gamesa (G128), Made (D13W), | Vestas (V90), Sinovel (1500,3000), GE(GE77), Suzlon(S88-Markll), Gamesa(G90), Guardian (U.P 1500), NagMicon (NM80),

Integrated wind farm when compared to conventional synchronous generator under

Wind farm are generally, back-to-back converters

provide a fast and accurate variable-frequency

excitation (± 30%) or fully rated converter

No concepts of “relative swing”, “rotor angle

deviation”, ‘’power angle characteristic’’, and no

It suffers from Low Voltage Ride through (LVRT)

# Schematic outline of DFIG WF

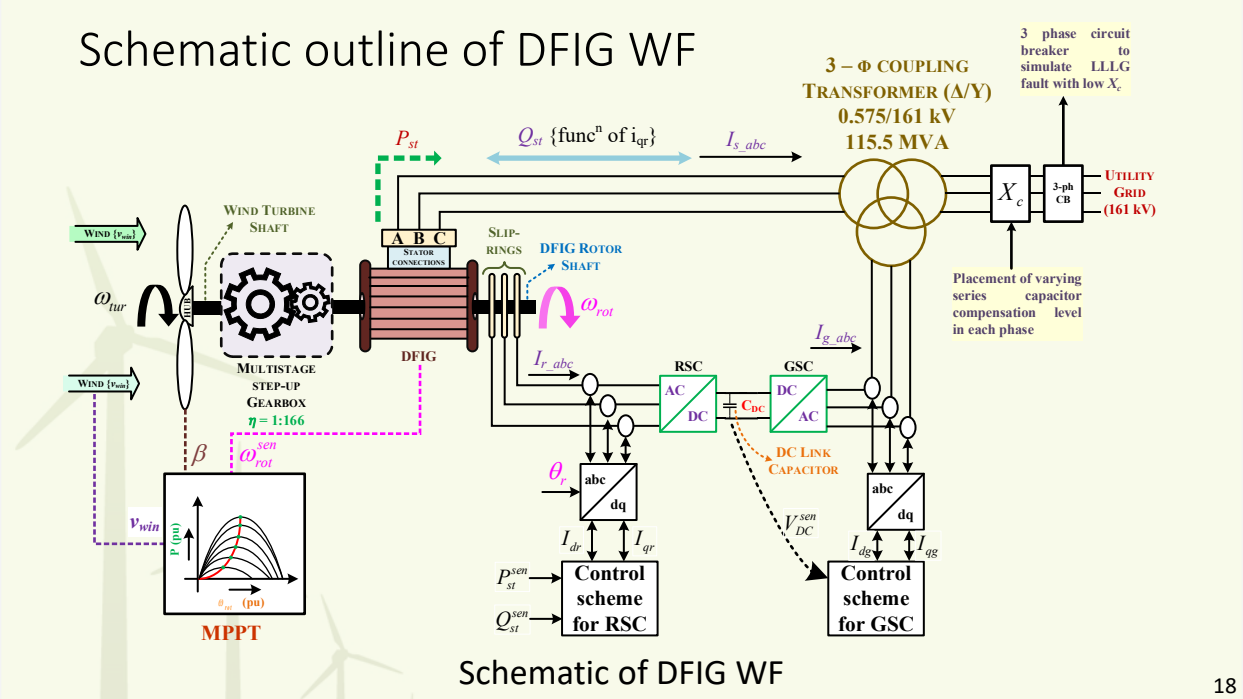
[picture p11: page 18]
STATOR; CONNECTIONS; MULTISTAGE; STEP-UP; GEARBOX = 1:166; SLIP-; RINGS; DFIG; RSC; GSC; DFIG ROTOR; SHAFT; – Φ COUPLING; TRANSFORMER (Δ/Υ) 0.575/161 kV 115.5 MVA; WIND TURBINE; SHAFT ωtur; ωrot; WIND {vwin}; UTILITY; GRID (161 kV); Pst; Qst {funcn of iqr}; DC LINK; CAPACITOR; CDC HUB; sen ωrot; Is_abc; abc; Ir_abc β; vwin; Control scheme for RSC; sen Pst; sen Qst; Control; scheme for GSC; sen VDC; abc dg I; MPPT P ⁽pu⁾; series; capacitor; compensation; level; breaker; simulate; LLLG; Ig_abc

3 phase circuit
fault with low Xc

in each phase X

Placement of varying

Schematic of DFIG WF

1 | 1 3 | 2 | 3 ( ) | ( ) 2 | 2
P | C | A v | C | r | v m | p | air | s | w | p | air | wt | w
= | = ρ | ρ π

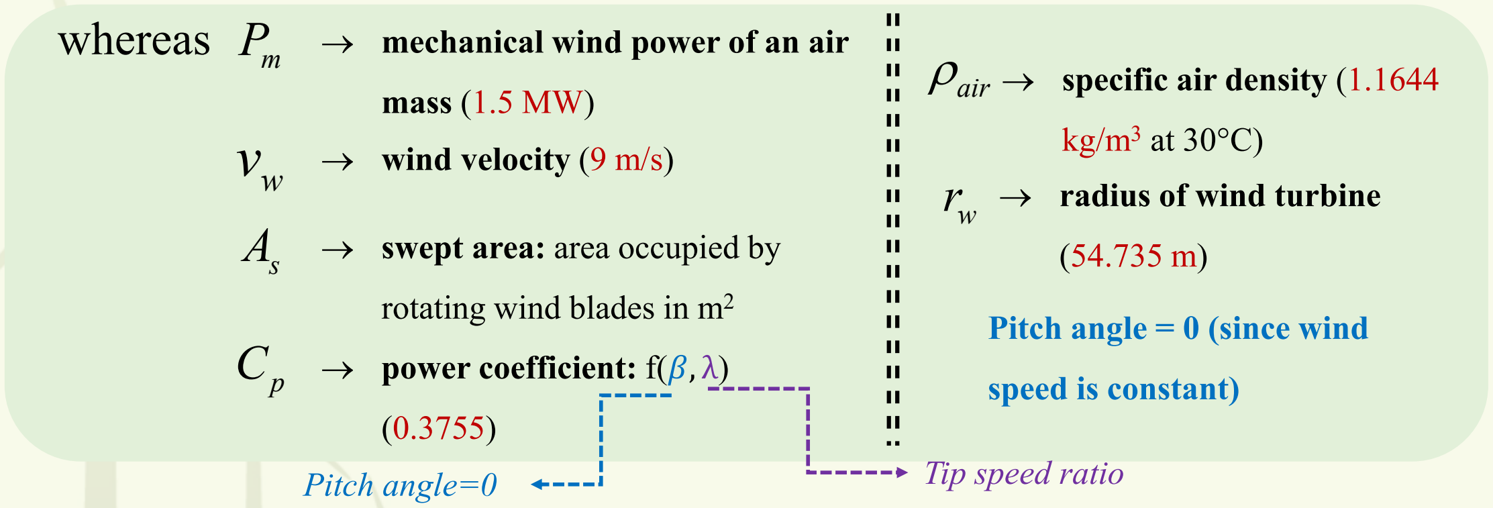
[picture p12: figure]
whereas; → mechanical wind power of an air; mass (1.5 MW); → wind velocity (9 m/s); → swept area: area occupied by; rotating wind blades in m²; → power coefficient: f(β, λ); Pitch angle=0; Tip speed ratio; ρair; → specific air density (1.1644; → radius of wind turbine; Pitch angle = 0 (since wind; speed is constant)

## Reference: [1], [12]

# Design of the wind turbine and gear mechanism

21
116 0.5176 | 0.4 | 5 | 0.0068
1 | 1 | 0.035

i p

i

C | e
λ β | λ
λ
− æ | ö
= | − | − | + ç | ÷ è | ø = | −

# Design of the wind turbine and gear mechanism

# Calculation for stator and rotor powers (formulas)

# Eqn. 1

P | P | P t | s | r = | + P
m | m | r

# =τω P

s | em | s

=τω

tur | DFIG
total | r | m | em | r
J | J

d
J | F
dt
ω τ | τ | ω

+

= | − | −

# Eqn. 2

# Eqn. 3

P | P m | t
= P | P P r | t | s
= | − P
r | m | r | em | s
= | − τ ω τ ω | s | r
r | em | s
s
P | ωω
τ | ω
| ω
æ | ö −
=− | ç | ÷ è | ø

# Eqn. 4

# Eqn. 5

# Eqn. 6

# Eqn. 7

# Eqn. 7

P | sP r | s
=−

# Eqn. 8

1

t
s

P
P
s

=
− | Eqn. 9
s | r

s

s

ωω
ω

−

# Whereas

=

# List of symbols and notations

:

tur | DFIG J and J

# Aggregated inertias of the turbines and the generators

:

# em τ and F

# Electromagnetic torque of DFIG and coefficient of friction

: P
m

# Mechanical power

: m τ

# Mechanical torque

: ωr

# Rotor angular speed

: P
s

# Stator power

: Pt

# Total power

: P
r

# Rotor power

# Calculation for stator and rotor powers (actual values)

## Wind speed = 9 m/s (constant)

## Synchronous speed = 1200 RPM (126 rad/sec)

# Summary of power flow

# •DC-link voltage

# 22 max 3*

2 2 *

2

575
3 *1
938.97

1.225*938.97

2

1150

.5%

dc | r a

V

# Safety f

to

# ctor

V m

# V lt

# Vol

æ | ö | ü ≥ ç | ÷ | ï
è | ø =
ý = | ï =
= | þ =

# For a 575 V, 100 MVA, 60 Hz system

# - RSC rating

# DFIG draws a lagging reactive power of 0.712 MVAr during motoring mode

* | 0.712 MVAr
| 0.214 MVAr
Q | s r
=× | ü
ý
= | þ

# Eqn. 16

( ) ( )

2 | 2 * | *
2 | 2 0.3162 | 0.214 | 0.382224 MVA
VA | P | Q RSC | r | r
ü = | + | ï
ý
= | + | = | ï
þ

# Eqn. 17

max

382224.2 383.78A
3 | 3 575
rms | RSC
RSC
| r

# VA I

V

= | = | =
× | × 2 | 2 383.721 A 542.75 A pk | rms
RSC | RSC I | I = | × | = | × | =

# Eqn. 18

# Eqn. 19

7% | 542.75 A 38.002 A pp
RSC I | of = | =

# Eqn. 20

| | | 1.3 { | | }

754.98 A

IGBT | pk | pp
RSC | RSC | RSC I | I | I = | × | + | üï
ý
= | ïþ

# Eqn. 21

# The voltage rating is selected as 1150 V, AMM800GA176D is a suitable module available in the market

# - GSC Rating

6 1.154 10 | 1158.5161 A
3 | 3 575
rms | GSC
GSC | LV
| xfmr

# VA I

V

×
= | = | =
× | ×

# Eqn. 21

2 | 2 1158.5161 A 1638.3892 A pk | rms
GSC | GSC I | I = | × | = | × | =

# Eqn. 22

7% | 1638.3892 A 114.6872 A pp
GSC I | of = | =

# Eqn. 22

1.3 { | }

2278.93 A

IGBT | pk | pp
GSC | GSC | GSC I | I | I = | × | + | üï
ý
= | ïþ

# Eqn. 23

# The voltage rating is selected similarly to RSC, as 1800 V, MG7405WZ is a suitable module available in the market

# Specifications of the system under study

## Three-phase mutual inductance

## Positive-sequence parameters

R1 = 5.1842 Ω
L1 = 0.34379 H

## Negative-sequence

## parameters

R0 = 15.553 Ω
L0 = 1.0314H
No. of wind turbines | 66
Frequency | 60 Hz
Pole pairs | 3

## Output Voltage level

of DFIG | 575 V
Grid voltage level | 161 kV
Transformer | 161 kV/575 V (Y/Δ) , 115.5 MVA
DC link voltage | 1150 V

## Rating of each wind

turbine | 1.5 MW
Grid voltage level | 161 kV
Power rating | 100 MVA
Power coefficient | 0.3755
Tip speed ratio | 6
Gear ratio | 1:166

## Wind turbine

radius | 54.735 m
DC link voltage | 1150 V
Wind Speed | 9 m/s

# - Compensation level

% | 100%

%
100

C

L

C | L

X C
X
C
X | X
ü = | × | ï

ý
ï = | × | þ

# Eqn. 24

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
CV f | P

π

π

ü =
ï
ý =
ï
æ | ö ç | ÷ è | ø | þ

# Eqn. 25

Outer control
loop of GSC

Inner control
loops of RSC

SFOCS based PI/FLC for DFIG along with PSS controller to the GSC

# Control scheme for RSC

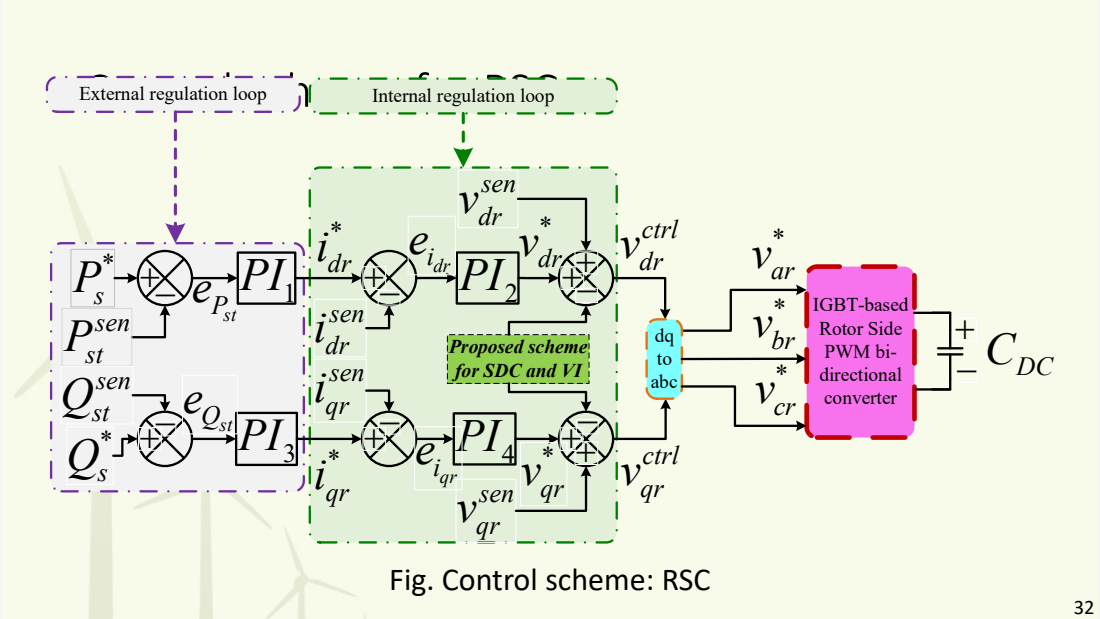
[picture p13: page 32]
sen Pst; sen Qst; sen dr; sen qr; ctrl dr v; ctrl qr v; Pst; Qst; External regulation loop; Internal regulation loop; IGBT-based Rotor Side PWM bi- directional converter; CDC; sen dr v; sen qr v; abc +

Proposed scheme
for SDC and VI

Fig. Control scheme: RSC

# Control scheme for GSC

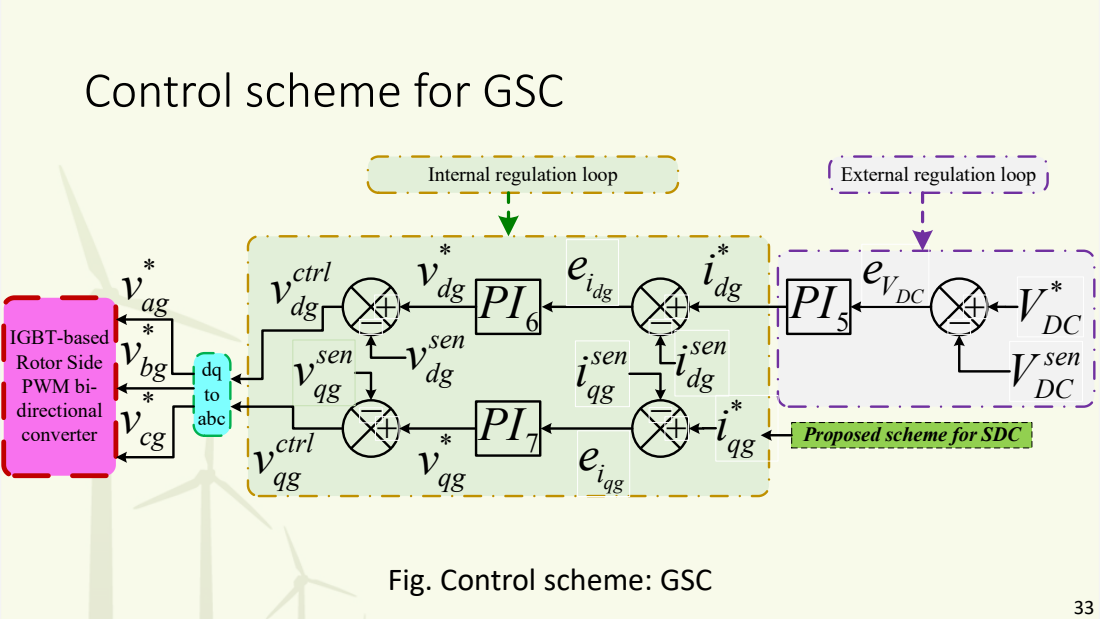
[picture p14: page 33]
sen VDC; * VDC VDC; ctrl dg v; ctrl qg v; sen dg; sen qg; sen; IGBT-based Rotor Side PWM bi- directional converter; dq to abc

Internal regulation loop

External regulation loop

Proposed scheme for SDC

Fig. Control scheme: GSC

# Proposed Control Scheme for RSC

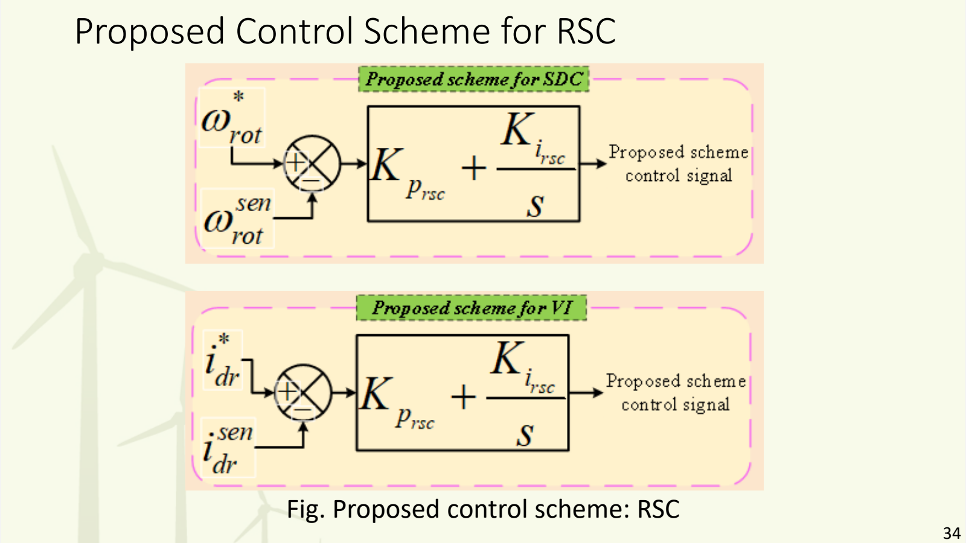
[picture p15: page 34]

# Fig. Proposed control scheme: RSC

# Proposed Control Scheme for GSC

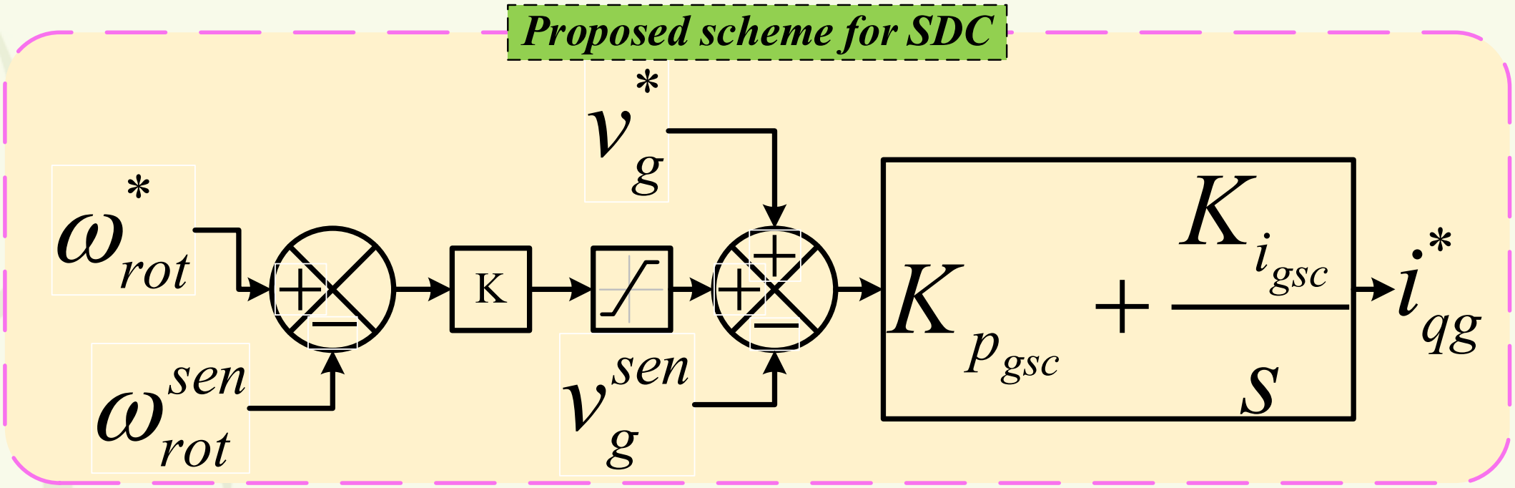
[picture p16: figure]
* ωrot; sen ωrot; sen g; gsc; Proposed scheme for SDC

# Fig. Proposed control scheme: GSC

# - 3 levels of compensation

# - 0 to 2 sec: 2% - 2 to 4 sec: 20% - 4 to 10 sec: 60%

# - Cases of simulation

# 1. Without any controller 2. Controller only at GSC 3. Controllers at GSC + RSC 4. VI-SDC in RSC

# Modelling of SSR

# - LLL-G fault

# - Created at 2.5 sec - Cleared at 2.6 sec

# Results

## Electromagnetic Torque Case 1 (0.45 pu/div)

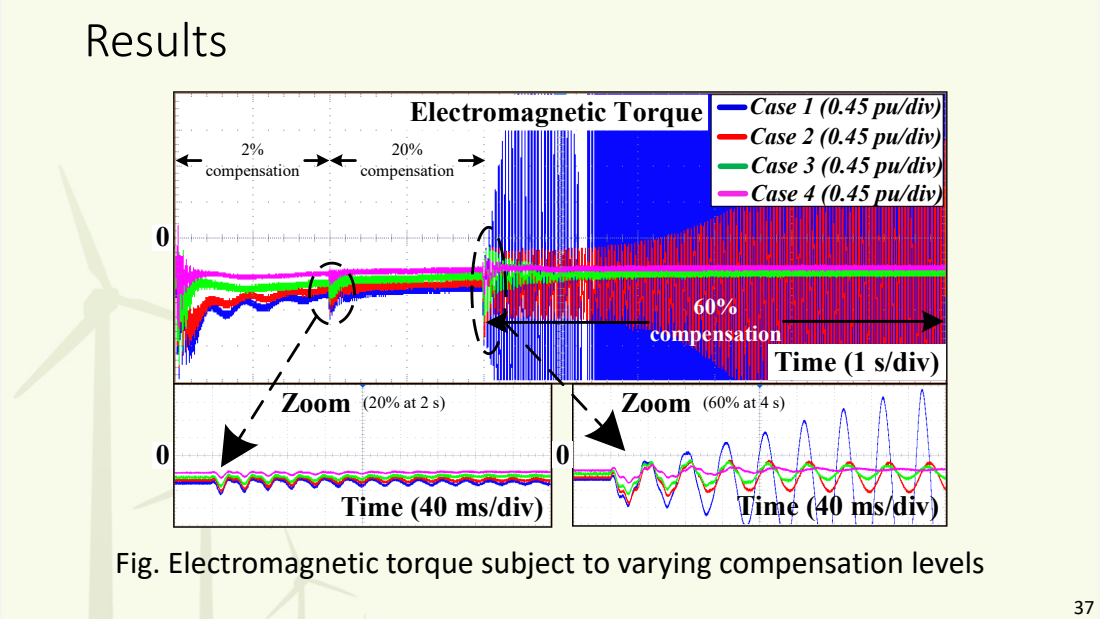
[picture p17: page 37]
Zoom; Time (1 s/div); Time (40 ms/div); 2% compensation; 20% compensation; 60% compensation

Case 2 (0.45 pu/div)
Case 3 (0.45 pu/div)
Case 4 (0.45 pu/div)

Fig. Electromagnetic torque subject to varying compensation levels

## Electromagnetic Torque

### Case 1 (0.7 pu/div)

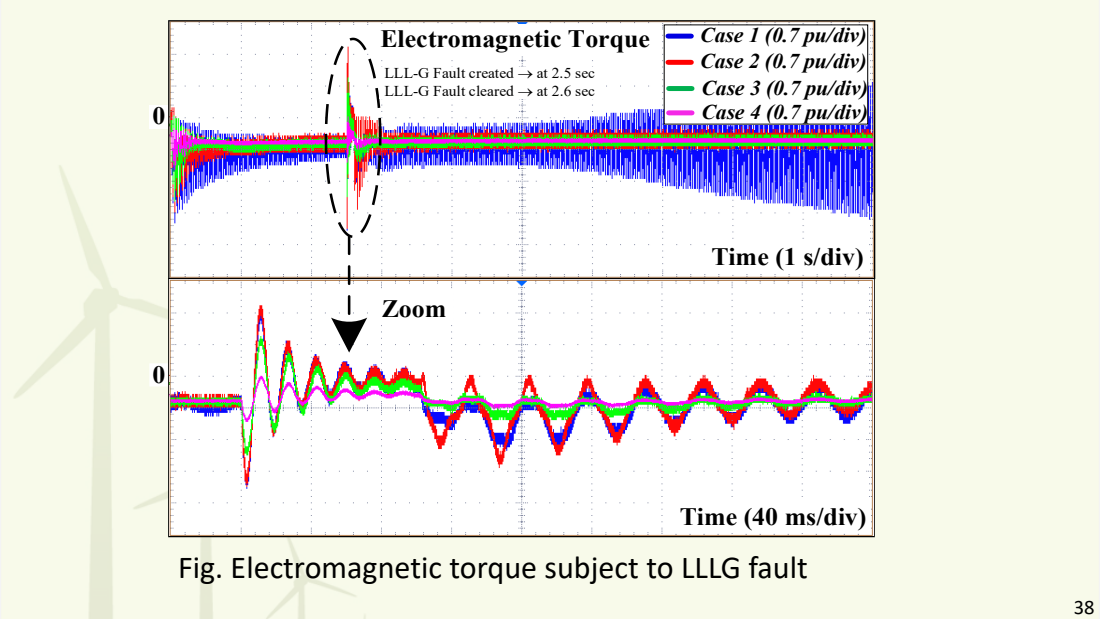
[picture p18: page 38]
Zoom; Time (1 s/div)

Case 2 (0.7 pu/div)
Case 3 (0.7 pu/div)

LLL-G Fault created → at 2.5 sec
LLL-G Fault cleared → at 2.6 sec

0 Case 4 (0.7 pu/div)

Time (40 ms/div)

Fig. Electromagnetic torque subject to LLLG fault

# ▪Machine Learning application to

# DFIG based WTGs

## - Objectives

## - Introduction

## - Series compensation and historical SSO event

## - Conventional Methods to identify SSO modes

## - Limitations of Conventional SSO Methods

## - Data Driven Methods for SSO Studies

## - Various ML classification algorithms used for SSO identification

## - Simulation Results and Discussion

## - Conclusion

## - References

# CONTENTS

# 1) To design the DFIG-based wind farm based modified IEEE first benchmark model

# 2) To apply the control strategy for the early prediction of sub-

synchronous oscillation (SSO) conditions.

# 3) To study the different machine learning models for fast severity predictions 4) To collect the dataset and train the multilayer perceptron (MLP) model

5) Comparative analysis of MLP, SVM, LR, KNN, NB, XGB, AdaBoost,

# RF, and DT methods with training and testing accuracy

# 6) To test the performance evaluation of the model by using the confusion matrix

# Objectives

# Why a need for series compensation & Advantages of series compensation

- A new wind energy power plants can be integrated into the existing national grid through dedicated or existing transmission lines by increasing the power transfer capability using series compensation (SC) or FACT devices [8]. Installing SC in a long transmission line is an inexpensive and efficient way to improve the capability

of power transfer of an existing transmission line [9].

# ❖Why did SSR occur in WF?

➢The problem that may arise because of SC in a long transmission line is Subsynchronous resonance (SSR), which can lead to shaft failure and power system instability [10],[11]. Also, the expansion of renewable generation significantly increases the severity and possibility of sub-synchronous oscillation (SSO) issues in

modern power systems.

# Historical events of SSO- China and USA

Year | Location | SSO Type | Severity | Reference
2015 | Hami | SSCI | Failure | [3], [4], [5]
2012 | Guyuan | SSR, SSCI | Failure | [6], [7]
2011 | Shangdu | SSR | Test | [4], [6], [10]
2009 | ERCOT | SSR, SSCI | Failure | [9], [1], [4]
1987 | Chester | SSTI | Test | [8], [2], [5], [6]
1983 | Ontario | SSTI | Test | [4]
1980 | Square butte | SSTI | Test | [7], [9], [8], [4]
1978 | Cholla | SSR | Test | [7], [5], [1]
1976 | Navajo | SSR | Test | [5], [2], [3]
1970 | Mahave | SSR | Failure | [2], [3], [1]

### Table 1- Major SSO Events

# Drawback of SSR occurs/reasons

- Sub-synchronous oscillations (SSO) in wind farms occur for two main reasons: (1) interaction of wind turbines with the series compensated grid and (2) interaction of wind turbines with the weak grid [16]. The severity of SSO depends on several factors, among which wind speed, level of series compensation, and number of wind

turbines in service can be identified as major contributors.

# - Accordingly, lower wind speeds, higher compensation levels, or an increasing number of wind turbines will worsen the severity of SSO. However, some SSOs occur even at low levels of series compensation. The 2012 Guyuan incident can be

cited as an example.
❖Solution of SSR Occurrence.

➢Therefore, to mitigate the impact of SSOs, early prediction of their dominant severity modes is essential for developing effective control strategies. This research proposes to develop an algorithm to anticipate severe SSO and send early warning signals to activate necessary mitigation controls, thereby preventing the escalation of

these events.

# Conventional Methods vs Machine Learning in Power Systems

Feature/Aspect | Conventional Methods | Machine Learning
Modeling Approach | Equation-based (deterministic) | Data-driven (probabilistic or pattern-based)
System Complexity | Limited to simple/linear systems | Handles nonlinear and complex systems
Adaptability | Low — requires manual tuning | High — adapts automatically with new data
Data Usage | Limited use of data | Learns directly from historical and real-time data
Fault Detection | Reactive (after-the-fact) | Predictive (early detection)
Load Forecasting Accuracy | Lower for irregular patterns | Higher, especially with variable loads
Scalability | Hard to scale with system growth | Scales easily with more data & variables
Pattern Recognition | Poor unless explicitly modeled | Excellent — finds hidden trends automatically
Handling Uncertainty | Sensitive, needs assumptions | Robust to noise and uncertainty
Maintenance Optimization | Manual or rule-based scheduling | Predictive maintenance and automated optimization

Advantages of ML algorithms in solving the same SSR Problem.

# Machine learning (ML) methods have been employed for mode

identification in SSO events [27].

# 1) These methods effectively extract nonlinear electrical characteristics

# 2) It can quickly deliver mode predictions based on online measurement

data.

# ML methods are used to solve this SSR issue

ML Classifier | | Ref
Multiple support vector machine (SVM) classifier | In this method, three features reflecting different SSO and interference levels are identified by analyzing historical PMU data and used as inputs to the multi-SVM classifier. | [28]
Convolutional neural network (CNN)-based method | For mode identification, utilizing a comprehensive SSO dataset | [29]
Long Short-Term Memory (LSTM) | Neural Network approach for estimating the dominant mode based on Synchrophasor data | [30]
Extreme Learning Machine (ELM)--based classifier | For the rapid and accurate recognition of SSOs | [31]
SVM algorithm | The Fast Fourier Transform (FFT) is used to extract the sub-synchronous frequency components from the PMU current phasor. used to find harmful SSO components. Three factors, namely, amplitude attenuation, frequency susceptibility, and energy accumulation, are then used to determine whether to send an alarm. | [32]
Decision tree (DT) | For suspected SSO, FFT analysis is performed to calculate the amplitudes and frequencies of SSO components. Then, an alarm signal will be sent if the frequency is close to the torsional vibration frequency of the generator shaft, the amplitude is high, or it lasts for extended periods. | [33]

Table 3- Previous studies literature summary of machine learning methods to solve SSO problems

# System Under Study

### Wind Farm

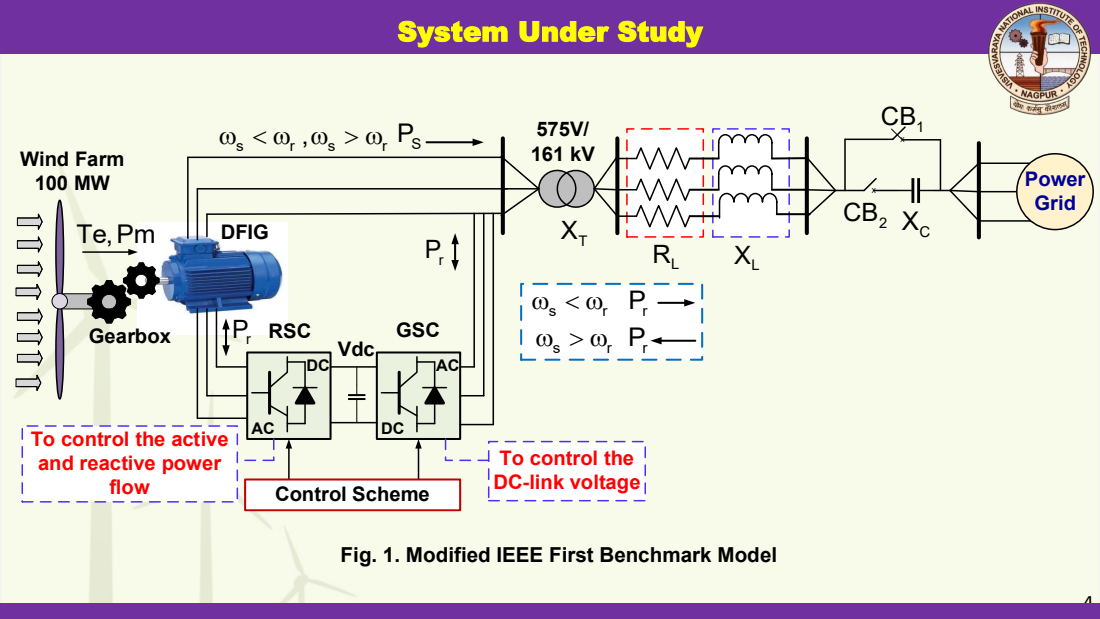
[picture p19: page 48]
Gearbox; DFIG; GSC; RSC; Vdc; Control Scheme; Power; Grid XT; flow

To control the active
and reactive power

To control the
DC-link voltage

Fig. 1. Modified IEEE First Benchmark Model

- When a small WF, whenever an SSO occurred, that time, a PS engineer can easily tell whether the system is non-SSO (stable), Non-severe SSO, or Severe SSO, but when have a large WF, it means, suppose 1000 connecting DFIGs, then that particular case PS engineer can’t say system is Non SSO (stable), Non severe SSO or Severe SSO has occurred, in which individual DFIG generators' by using graphical analysis. It is very critical to identify the system’s behavior. So, to overcome these issues, the proposed research is focused on ML algorithms that can be easily applied to solve the above problem.

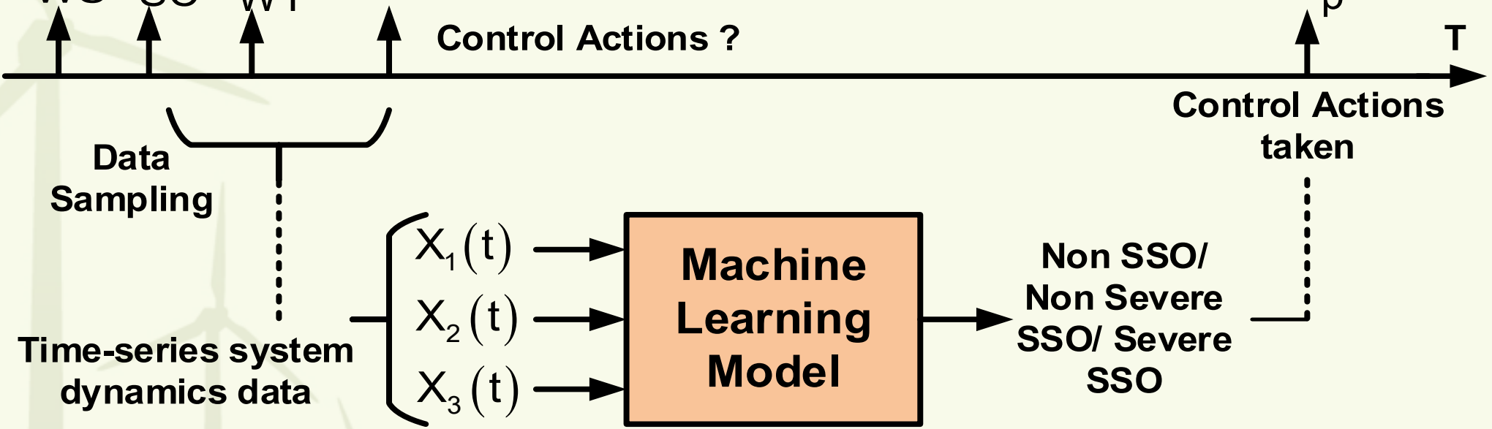
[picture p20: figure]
Control Actions ?; Machine Learning Model; Non SSO/ Non Severe SSO/ Severe SSO; Control Actions; Data; taken; Sampling; Time-series system dynamics data

## Fig. 2. Illustration of the severity prediction task

# Control Strategies

p

## t SC tWS t

## WT t

# Machine Learning Models for Fast Severity Predictions

+

(a) Logistic Regression (LR)
algorithm

# Machine Learning Models for Fast Severity Predictions

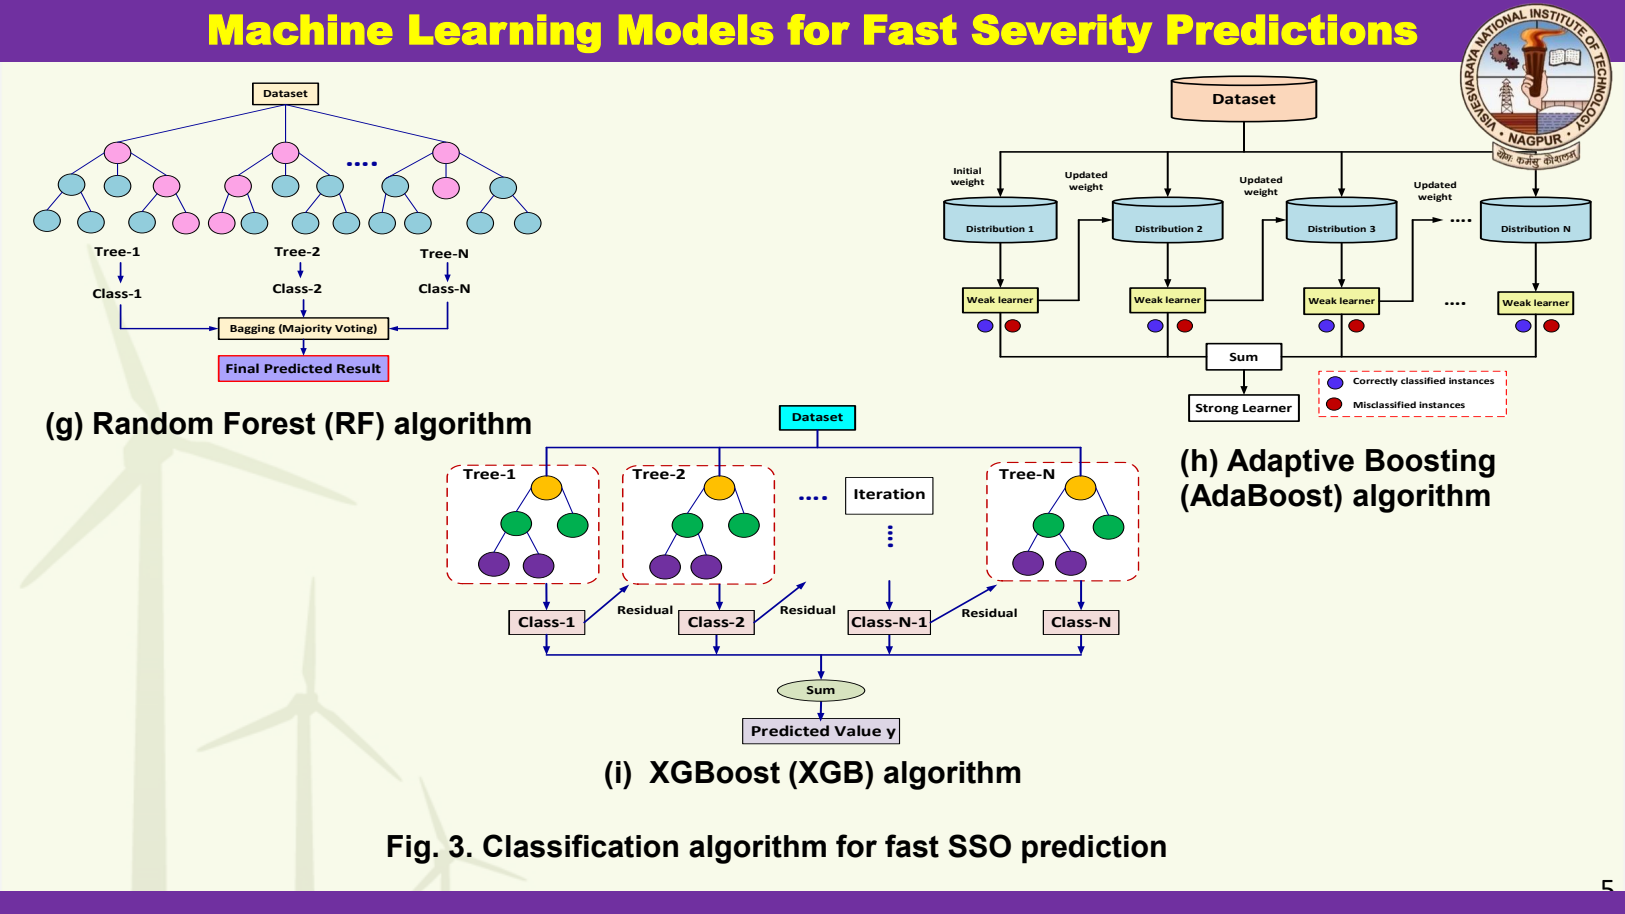
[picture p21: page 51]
Dataset; Tree-1; Tree-2; Tree-N; Class-1; Class-2; Class-N; Weak learner; Sum; Strong Learner; Distribution 1; Distribution 2; Distribution 3; Distribution N; Initial weight; Updated weight; Misclassified instances; Predicted Value y; Iteration; Class-N-1; Residual; (h) Adaptive Boosting (AdaBoost) algorithm

Bagging (Majority Voting)

Final Predicted Result

Correctly classified instances

(g) Random Forest (RF) algorithm

(i) XGBoost (XGB) algorithm

Fig. 3. Classification algorithm for fast SSO prediction

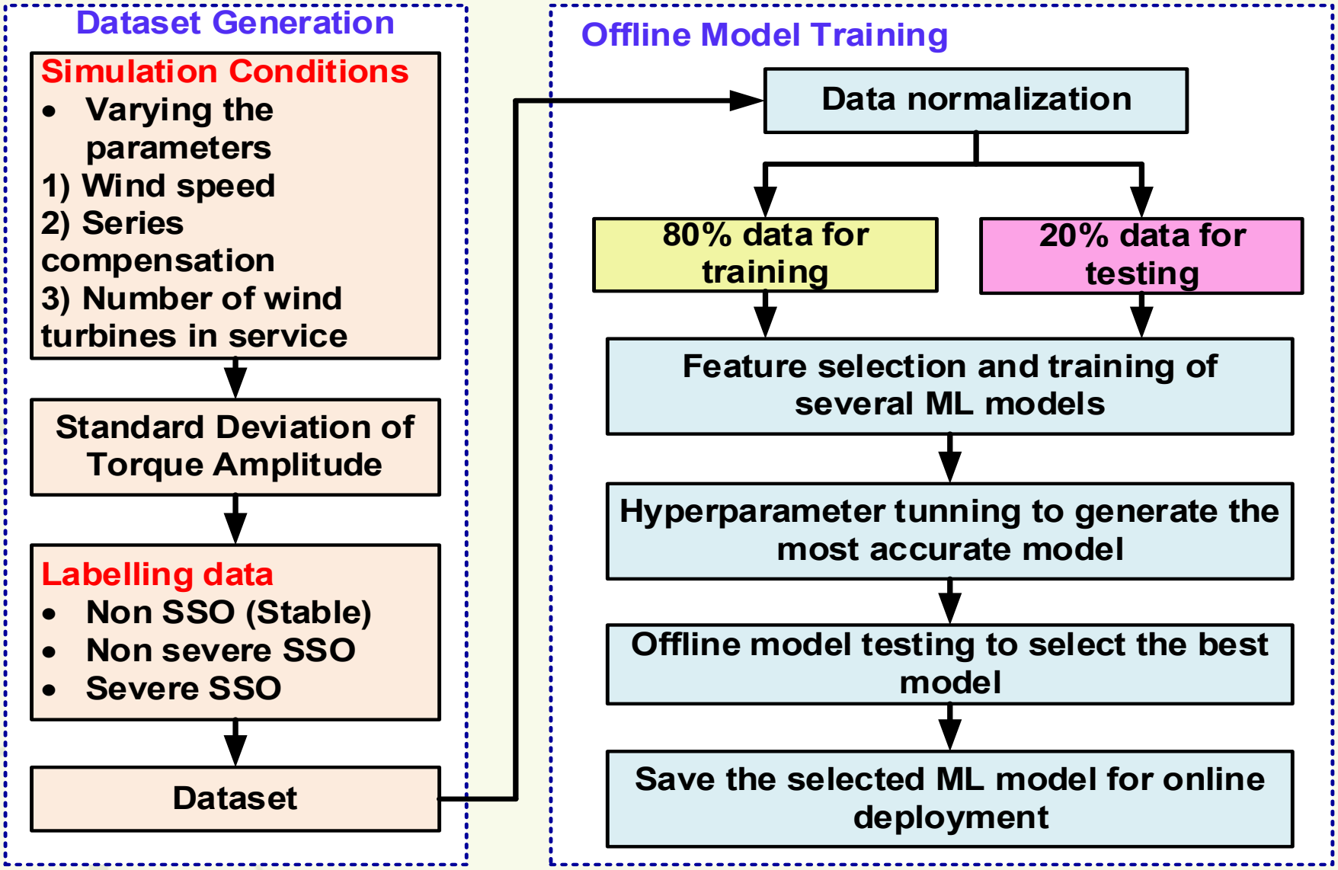
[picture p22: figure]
Simulation Conditions • Varying the parameters 1) Wind speed 2) Series compensation 3) Number of wind turbines in service; Data normalization; Labelling data • Non SSO (Stable) • Non severe SSO • Severe SSO; 80% data for training; Feature selection and training of several ML models; Dataset; Hyperparameter tunning to generate the most accurate model; model; Save the selected ML model for online deployment; Standard Deviation of Torque Amplitude; 20% data for testing

## Fig. 4. Classification of TSA Study

Methods | 5

# Developing the training dataset

### Offline model testing to select the best

Dataset Generation | Offline Model Training

## Table 4- The summary and comparisons of previous reported studies to label the dataset

# Training dataset labelling criteria

Ref. | Label determination method | Class-1 | Class-2 | Types of classifiers
[26] Using FFT spectral analysis | | SSO Feature Vectors: These are labelled as "+1" to indicate the presence of sub-synchronous oscillations. | Non-SSO Feature Vectors: These are labelled as "−1" to signify the absence of sub-synchronous oscillations | Multi-SVM classifier
[30] | According to the parameters K, M, and N established by employing the amplitude of percentage | If a sample's amplitude percentage exceeds a specific large value (denoted as M%), it is likely to be a real SSO component. Such samples are labelled as "need to pay attention" | If a sample's amplitude percentage is below a certain low value (denoted as N%), it is considered non-harmful and labelled as "no need to pay attention." | SVM classifier
[31] | Components K and M, defined by amplitude and saliency, indicate the amount of frequency amplitude fluctuation. | A feature vector can be labelled as "Suspected SSO" if there is at least one sub-synchronous component whose amplitude percentage exceeds a predetermined threshold, denoted as K%. | A feature vector is derived from "Ambient" based on the characteristics of the data. | DT classifier
Propose d work | Torque Amplification (TA) | HTAS: If a sample's TA exceeds a specific large value, it is likely to be a real SSO component and such samples are labelled as "Severe SSO". | LTAS: if a sample's TA is below a certain low value, it is considered non-harmful and labelled as "Non SSO." | MLP classifier

# Multilayer Perceptron Model Training

X1 X2 X3 W3 W2 W1 ....

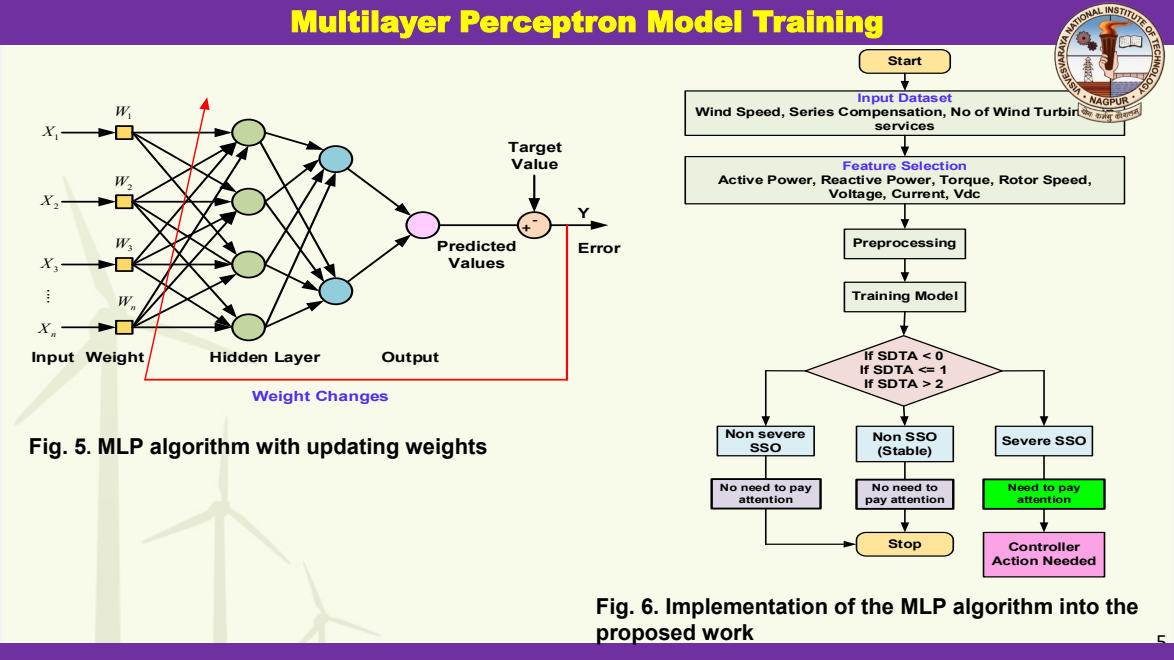
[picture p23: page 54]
Input Weight; Hidden Layer; Output X; Target Value; Predicted Values; Weight Changes; Start; Stop; Input Dataset; services; Non SSO; Severe SSO; (Stable); If SDTA < 0 If SDTA <= 1 If SDTA > 2; Feature Selection; Training Model; Non severe SSO; Controller Action Needed; proposed work

Wind Speed, Series Compensation, No of Wind Turbines in

Active Power, Reactive Power, Torque, Rotor Speed,

Voltage, Current, Vdc

Preprocessing Fig. 6. Implementation of the MLP algorithm into the
Error

Fig. 5. MLP algorithm with updating weights

No need to pay
attention

No need to
pay attention

Need to pay

# - The study involved the development of a dataset comprising 10,649 operating

conditions, achieved through variations in WS, SC, and WT.

# - The WS below the cut-in WS (3 m/s) and cut-out WS (25 m/s). To generate data points for the level of SC, a range of 15% to 80% is used, while the WT varies between 31-67 (50%-100% of the capacity of the WF). These will be inputs to the

simulation model in Figure 1.

- The simulation model initially operates with minimal SC (CB1 closed, CB2 opened). At t = 2s, it is connected to a high SC level to simulate the system's response when a WF is radially connected to a series-compensated line (CB1 opened, CB2 closed). It is assumed that the circuit breakers of the disconnected transmission line successfully re-close after a 1-second interval, returning the

system to its initial operating configuration at t = 3s (CB1 closed, CB2 opened).

# Simulation scenarios

Parameters | Range | Variable Step
Wind Speed | 3 m/s – 25 m/s | 1
Series compensation | 15 % - 90% | 1
Number of wind turbines in service | 31- 67 | 1

# Different SC level with SSO conditions

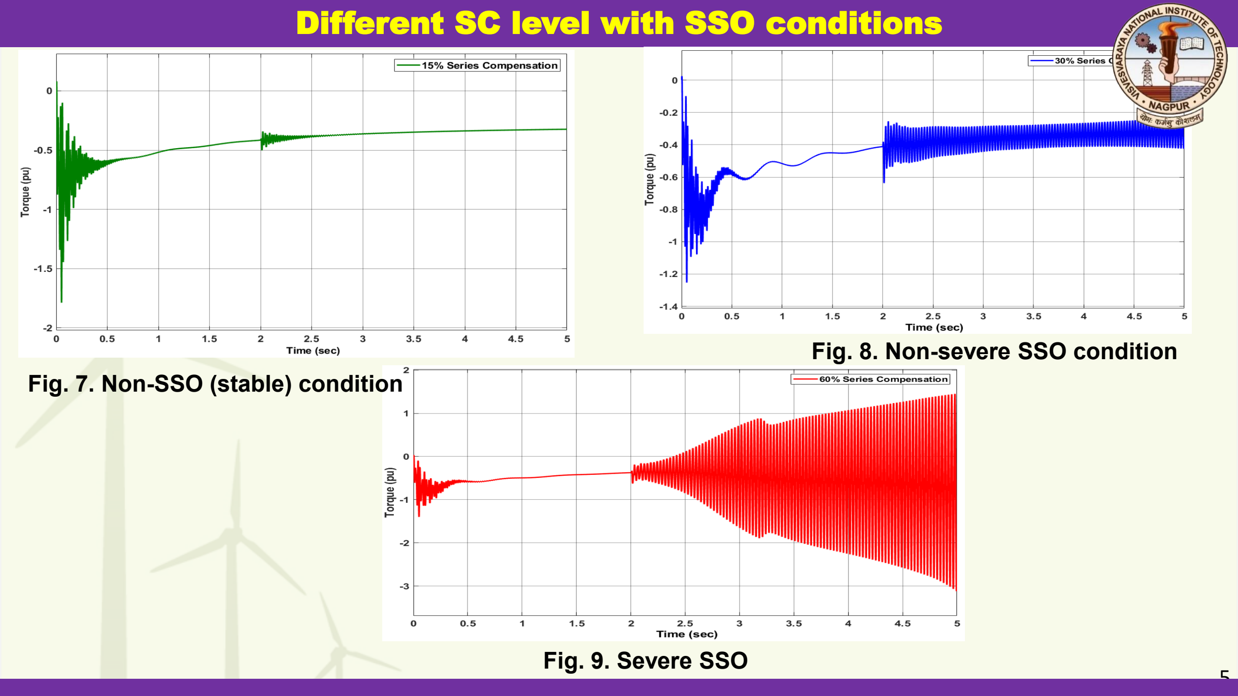
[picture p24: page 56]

## Fig. 9. Severe SSO

condition | 5

## Fig. 7. Non-SSO (stable) condition

## Fig. 8. Non-severe SSO condition

Fig. 10. Dynamic behaviour of the electromagnetic torque (Te) of different series compensation levels at 7 m/s wind speed: an SSO conditions analysis for (a) 15% series compensation; (b) 30% series compensation;

## and (c) 60% series compensation

# Distribution of input feature set- WS, SC, WT

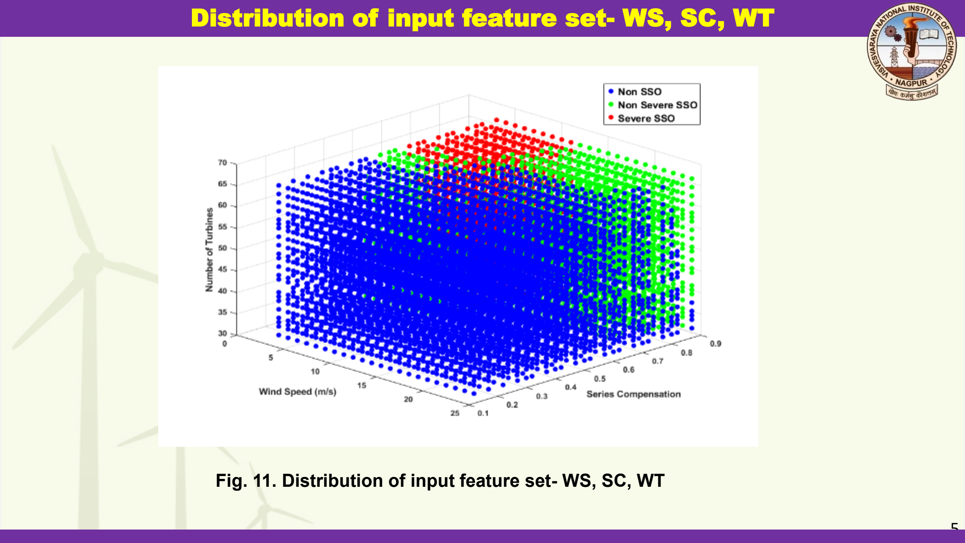
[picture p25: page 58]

## Fig. 11. Distribution of input feature set- WS, SC, WT

# Confusion Matrix

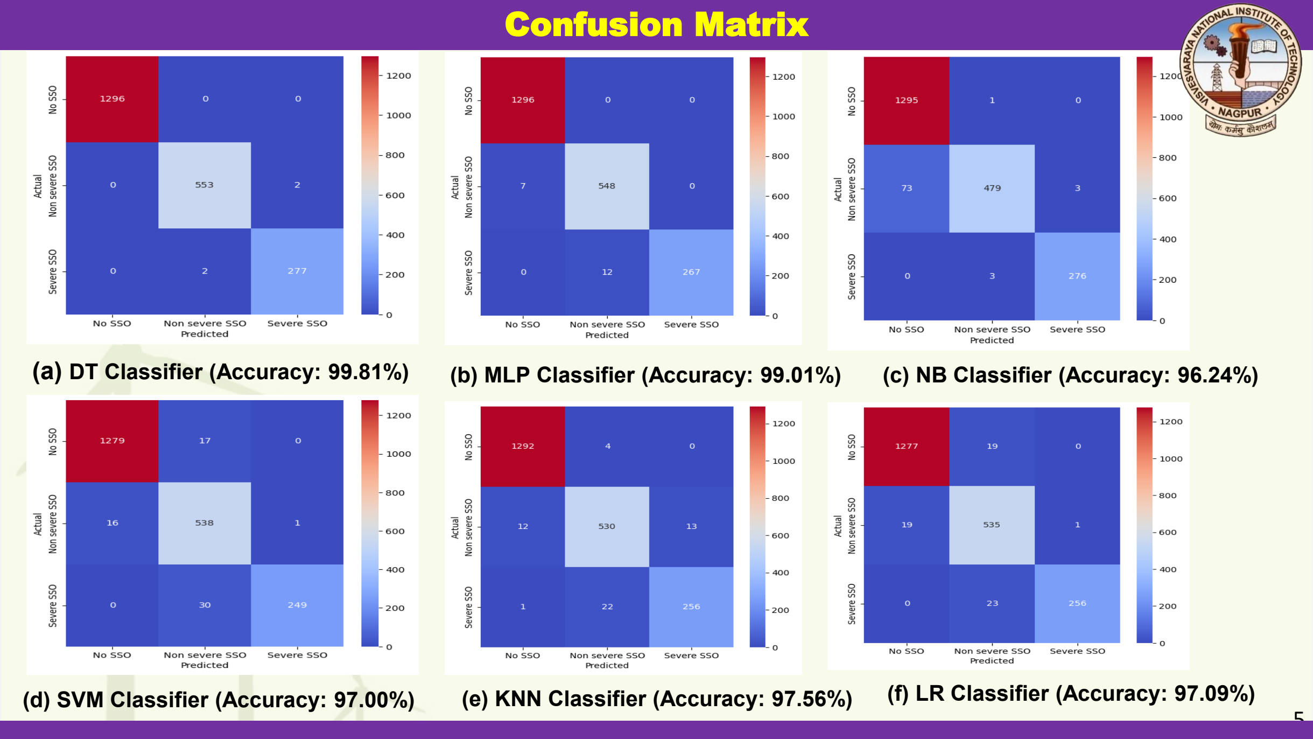
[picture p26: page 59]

(a) DT Classifier (Accuracy: 99.81%) | (b) MLP Classifier (Accuracy: 99.01%) | (c) NB Classifier (Accuracy: 96.24%)
(d) SVM Classifier (Accuracy: 97.00%) | (e) KNN Classifier (Accuracy: 97.56%) | (f) LR Classifier (Accuracy: 97.09%)

# Confusion Matrix

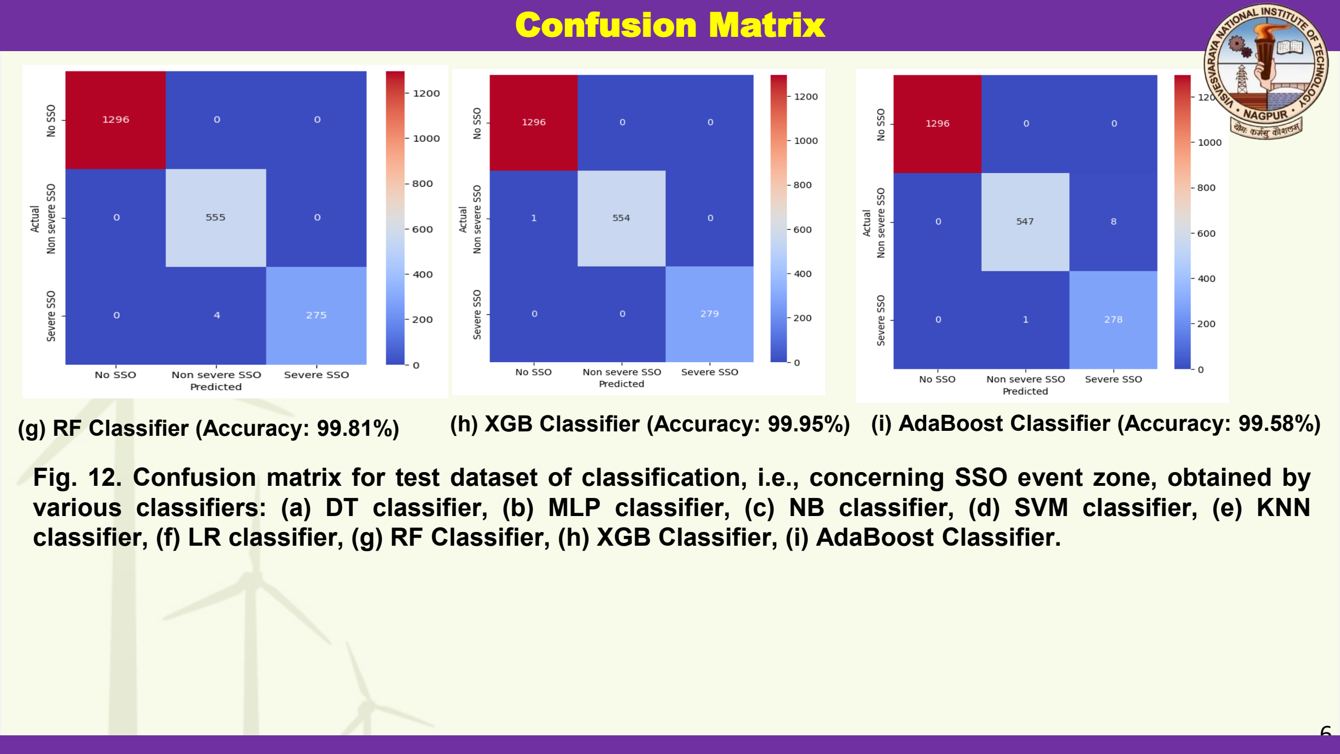
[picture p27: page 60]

Fig. 12. Confusion matrix for test dataset of classification, i.e., concerning SSO event zone, obtained by various classifiers: (a) DT classifier, (b) MLP classifier, (c) NB classifier, (d) SVM classifier, (e) KNN classifier, (f) LR classifier, (g) RF Classifier, (h) XGB Classifier, (i) AdaBoost Classifier.

(g) RF Classifier (Accuracy: 99.81%) (h) XGB Classifier (Accuracy: 99.95%) (i) AdaBoost Classifier (Accuracy: 99.58%)

1) Accuracy: In classification evaluation, using accuracy (ACC) is beneficial because it succinctly quantifies the proportion of correctly classified instances relative to the total number of instances.
2) Precision: The precision (also called positively predictive value) describes the capability of a model to identify a severe SSO condition's overall true positive prediction. It is represented as the ratio of the correct positive predictions to the number of samples labeled as positive.
3) Recall: The recall (also called sensitivity) gives the model the capability to identify all severe SSO conditions. Recall is described as the ratio of the number of correct positive predictions to the number of positive samples.
4) F1_Score: The F1-score is the harmonic mean of precision and recall, which inherently implies that a high F1-score can only be achieved if both precision and recall are high. If either is low, the F1-score will tend toward the lower value.

# Evaluation Matrices

## TP + TN Accuracy = TP + TN + FP + FN

## TP Precision = TP + FP

## TP Recall = TP + FN

## Precision ×Recall F1 Score = 2× Precision + Recall

## Table 6- Results of sequential feature selection

Input features | Accuracy (%)
NB | DT | MLP | SVM | KNN | LR | RF | XGB | AdaBoost
WS, SC, WT | 87.42 | 98.69 | 98.54 | 96.67 | 96.95 | 90.05 | 98.78 | 98.73 | 77.32
WS, SC | 87.09 | 96.15 | 94.84 | 95.63 | 96.06 | 90.14 | 96.15 | 96.15 | 78.26
WS, WT | 61.36 | 57.00 | 61.41 | 61.17 | 51.83 | 60.99 | 56.90 | 57.42 | 60.94
SC, WT | 75.87 | 77.79 | 78.03 | 78.03 | 72.63 | 76.48 | 77.09 | 77.79 | 76.20
WS | 61.08 | 60.42 | 60.85 | 60.85 | 54.51 | 60.99 | 60.42 | 60.42 | 60.42
SC | 76.95 | 78.03 | 78.03 | 78.03 | 72.96 | 76.95 | 78.03 | 78.03 | 78.03
WT | 60.85 | 60.85 | 60.85 | 55.92 | 60.85 | 60.85 | 60.85 | 60.85 | 60.85

## Table 7- Results of classification model performance in training and testing stages

Classification Technique | Best input features | Training | Testing
Accuracy (%) | Training time (s) | Accuracy (%) | Prediction time (ms)
NB | WS, SC, WT | 87.31 | 0.033 | 87.42 | 1.006
DT | WS, SC, WT | 99.46 | 0.040 | 98.69 | 1.009
MLP | WS, SC, WT | 98.93 | 39.649 | 98.40 | 127.241
SVM | WS, SC, WT | 97.66 | 0.315 | 96.67 | 155.508
KNN | WS, SC, WT | 98.79 | 0.045 | 96.95 | 80.848
LR | WS, SC | 91.78 | 0.115 | 90.14 | 1.001
RF | WS, SC, WT | 99.21 | 0.435 | 98.78 | 23.673
XGB | WS, SC, WT | 99.95 | 0.524 | 98.73 | 4.495
AdaBoost | WS, SC | 79.63 | 0.399 | 78.26 | 26.46

# Training performance of the implemented MLP algorithm

## Table 8- MLP model performance evaluation

Measurement Parameters | Non SSO | Non-Severe SSO | Severe SSO
Precision | 0.99 | 0.98 | 1
Recall | 1 | 0.99 | 0.96
F1-score | 1 | 0.98 | 0.98

Fig. 13. Training performance of the implemented MLP algorithm (a) accuracy vs epoch (b) loss vs epoch

- The proposed SSO prediction model can predict the occurrence of SSO and send alarm signals within 314.842 ms. the prediction time of the MLP model itself is only 0.06 sec. However, the total time taken for prediction of a non-SSO, non-severe SSO, or severe SSO increases up to 157.142 ms. Existing ML-based research works required the analysis of data windows of size 1 section on top of their model prediction times for the prediction of SSO. Hence, the proposed methods can be

## suggested as a much faster approach for the prediction and alarming of SSO conditions. To

understand the proposed SSO prediction algorithm, a further summary of the predicted class and the proposed actions is given in Table 9.

## Table 9- SSO model prediction and proposed control action taken

# MLP Models for Fast Severity Predictions

Prediction | Proposed Action
Non SSO | No action needed
Non-Severe SSO | Issue a warning signal
Severe SSO | Activation of SSO mitigation measures
Low confidence prediction | Alarms PSO for further investigations

- This study proposes an MLP algorithm to predict severe SSO conditions in DFIG-based WF connected to a series compensated lines that could trigger the wind generator protection devices.
- The IEEE's first benchmark model is used for dataset development.
- Three key factors affecting the severity of SSO: WS, SC, and WT are used as the attributes to train the proposed MLP classifier.
- The TA is used to determine the severity of the SSO.
- The MLP algorithm shows superior performance when compared with other ML algorithms. It has an accuracy of 99.01% and training and prediction times of 36.44 seconds and 0.06 sec.
- The total time taken for the proposed SSO prediction algorithm to predict the occurrence of severe SSO, non-severe SSO, and non-SSO is 157.142 ms.
- One of the key advantages of the proposed method over existing research is that this method uses an ML algorithm, which gives an idea regarding the confidence level of the prediction. This is crucial for modern power grid applications due to the dynamic nature of the power grid.

# Conclusion

Integrated wind farm when compared to conventional synchronous generator under

Wind farm are generally, back-to-back converters

provide a fast and accurate variable-frequency

excitation (± 30%) or fully rated converter

No concepts of “relative swing”, “rotor angle

deviation”, ‘’power angle characteristic’’, and no

It suffers from Low Voltage Ride through (LVRT)

Disturbance size | Time scale | Type of stability

Large disturbance

Long term: tens of seconds to a few minutes | Long-term frequency stability, Large-disturbance long-term voltage stability
Short term: 0.1–2 Hz to 0.1–10 Hz | Short-term frequency stability, Transient stability, Short-term voltage stability
Short to ultra-short term: 1~kHz | Large-disturbance converter driven stability

Small disturbance

Long term: tens of seconds to a few minutes | Small-disturbance voltage stability
Short term: 0.1–2 Hz to 0.1–10 Hz | Small-disturbance angle stability
Short to ultra-short term: 1~kHz | Resonance stability, Small-disturbance converter driven stability

A reorganized version of the power system stability classification.

- Power system are related to the damping of the electromechanical modes of oscillation.
- Local area mode of oscillation means one generator swings against the rest of the generator at a frequency of 1.0 to 2.0 Hz.
- Inter area mode of oscillation means it involves two coherent group or groups of generators swinging against each other at a

frequency of 1 Hz or less.

= ∑ φ ψ Flow chart of Small Signal stability Analysis

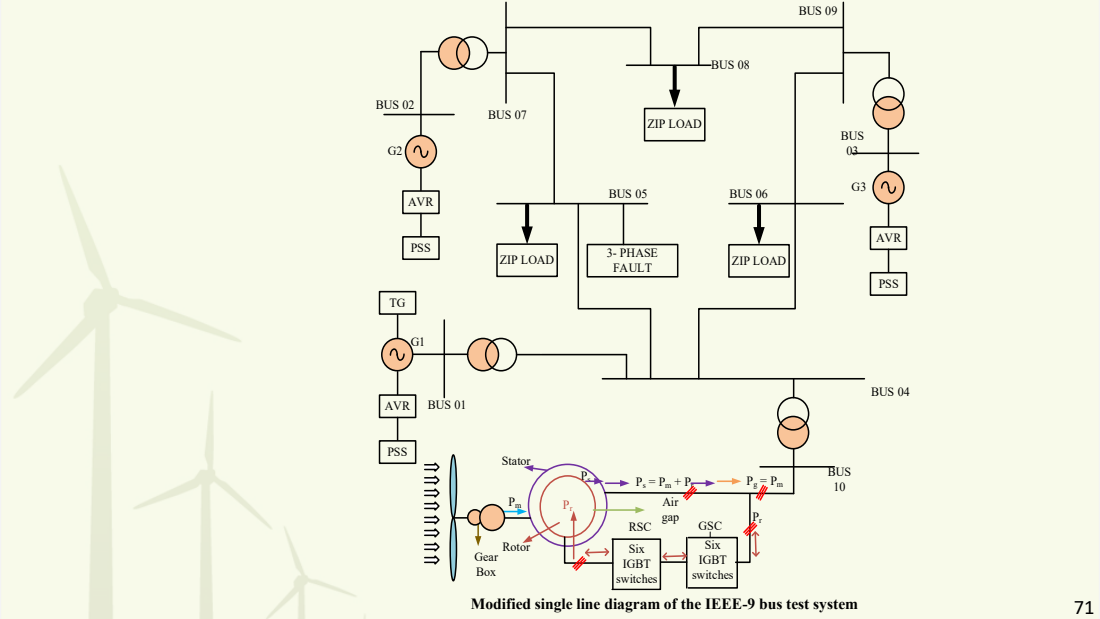
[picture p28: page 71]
Air; gap; Rotor; Stator; Gear Box; RSC; GSC; Six IGBT switches; 3- PHASE FAULT; BUS 02; BUS 07; BUS 05; ZIP LOAD; BUS 06; BUS 08; BUS 09; BUS 04; BUS 01; BUS 03; BUS 10; AVR; PSS

Modified single line diagram of the IEEE-9 bus test system

GS
GS

INTER AREA; BUS1; BUS5; BUS6; BUS7 BUS9; BUS11; BUS3; BUS10; Wind Farm; BUS8; Wind farm; Fault; Load; BUS2

Wind farm

Sending End Side (ARAE1)

Receiving End Side (ARAE2)

Two area test system (IEEE-11 Bus)

DFIG

IEEE-14 bus test system

# Conclusions

## ❑ Brief review and comparison of the different WECS, various topologies are

## described, the machines involved in WECS ,weaknesses and strengths of

different wind turbine generators are discussed.

## ❑ The topic research of power system stability with wind power penetration

## focuses on the modal analysis and time-domain simulations, through which

## the impact of wind power on power system oscillation modes and damping

performances are discussed.

[1] B. Lin and J. O. Okoye, “Towards renewable energy generation and low greenhouse gas emission in high-income countries: Performance of financial development and governance,” Renew. Energy, vol. 215, no. June, p. 118931, 2023, doi: 10.1016/j.renene.2023.118931.
[2] Z. Zhong, W. Hu, and X. Zhao, “Rethinking electric vehicle smart charging and greenhouse gas emissions: Renewable energy growth, fuel switching, and efficiency improvement,” Appl. Energy, vol. 361, no. September 2023, p. 122904, 2024, doi: 10.1016/j.apenergy.2024.122904.
[3] A. A. Eladl et al., “A comprehensive review on wind power spillage: Reasons, minimization techniques, real applications, challenges, and future trends,” Electr. Power Syst. Res., vol. 226, no. February 2023, p. 109915, 2024, doi: 10.1016/j.epsr.2023.109915.
[4] A. Qazi et al., “Towards Sustainable Energy: A Systematic Review of Renewable Energy Sources, Technologies, and Public Opinions,” IEEE Access, vol. 7, pp. 63837–63851, 2019, doi: 10.1109/ACCESS.2019.2906402.
[5] A. D. Bebars, A. A. Eladl, G. M. Abdulsalam, and E. A. Badran, “Internal electrical fault detection techniques in DFIG-based wind turbines: a review,” Prot. Control Mod. Power Syst., vol. 7, no. 1, 2022, doi: 10.1186/s41601-022-00236-z.
[6] M. Rahmani, G. Vinasco, M. J. Rider, R. Romero, and P. M. Pardalos, “Multistage transmission expansion planning considering fixed series compensation allocation,” IEEE Trans. Power Syst., vol. 28, no. 4, pp. 3795–3805, 2013, doi: 10.1109/TPWRS.2013.2266346.
[7] X. Xie, X. Zhang, H. Liu, H. Liu, Y. Li, and C. Zhang, “Characteristic Analysis of Subsynchronous Resonance in Practical Wind Farms Connected to Series-Compensated Transmissions,” IEEE Trans. Energy Convers., vol. 32, no. 3, pp. 1117–1126, 2017, doi: 10.1109/TEC.2017.2676024.
[8] R. Kumar, S. Diwania, P. Khetrapal, S. Singh, and M. Badoni, “Multimachine stability enhancement with hybrid PSO-BFOA based PV-STATCOM,” Sustain. Comput. Informatics Syst., vol. 32, no. November, p. 100615, 2021, doi: 10.1016/j.suscom.2021.100615.
[9] N. Verma, N. Kumar, S. Gupta, H. Malik, and F. P. García Márquez, “Review of sub-synchronous interaction in wind integrated power systems: classification, challenges, and mitigation techniques,” Prot. Control Mod. Power Syst., vol. 8, no. 1, 2023, doi: 10.1186/s41601-023-00291-0.
[10] R. G. Farmer, A. L. Schwalb, and E. Katz, “Navajo Project Report on Subsynchronous Resonance Analysis and Solutions.,” no. 4, pp. 1226– 1232, 1977.

# References

[11] J. Adams, C. Carter, and S. H. Huang, “ERCOT experience with Sub-synchronous Control Interaction and proposed remediation,” Proc. IEEE Power Eng. Soc. Transm. Distrib. Conf., pp. 1–5, 2012, doi: 10.1109/TDC.2012.6281678.
[12] L. Wang, X. Xie, Q. Jiang, H. Liu, Y. Li, and H. Liu, “Investigation of SSR in Practical DFIG-Based Wind Farms Connected to a Series-Compensated Power System,” IEEE Trans. Power Syst., vol. 30, no. 5, pp. 2772–2779, 2015, doi: 10.1109/TPWRS.2014.2365197.
[13] Y. Li, L. Fan, and Z. Miao, “Replicating Real-World Wind Farm SSR Events,” IEEE Trans. Power Deliv., vol. 35, no. 1, pp. 339–348, 2020, doi: 10.1109/TPWRD.2019.2931838.
[14] Y. Cheng et al., “Real-World Subsynchronous Oscillation Events in Power Grids With High Penetrations of Inverter-Based Resources,” IEEE Trans. Power Syst., vol. 38, no. 1, pp. 316–330, 2023, doi: 10.1109/TPWRS.2022.3161418.
[15] H. A. Mohammadpour and E. S. Seniour, “Sub-synchronous resonance analysis in DFIG-based wind farms: Definitions and problem identification - Part I,” 2014 IEEE Energy Convers. Congr. Expo. ECCE 2014, pp. 812–819, 2014, doi: 10.1109/ECCE.2014.6953480.

# References

## Mail ID: jawahar2049@gmail.com, jawahar3049@eee.vnit.ac.in

## Mobile No: 8000599400

# •THANK YOU

## Mail ID: jawahar2049@gmail.com

## jawahar3049@eee.vnit.ac.in

## Mobile No: 8000599400

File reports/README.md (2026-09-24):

# Technical Reports & Institutional Presentations

This directory catalogues the academic presentations, technical briefing notes, and project reports associated with the PAWAN SHAKTI development cycle at VNIT Nagpur.

---

## Document Index

### 1. Pawan Shakti Technical & Business Briefing Note
- **File Reference**: [`reports/Pawan_Shakti_Briefing_Note.docx`](./Pawan_Shakti_Briefing_Note.docx)
- **Author**: Koyaneni Yaswanth (Founder & Lead)
- **Academic Mentor**: Dr. Jawahar Bhukya (VNIT Nagpur)
- **Key Contents**:
  - Technical positioning of decentralized low-wind SSWT systems for inland India.
  - Evolution across Mark-3, Mark-4, and Mark-5 physical prototypes.
  - Academic paper integration: *"Affordable Low-Wind Rooftop Wind Turbine Energy System Design for Rural Electrification"* and *"A Space-Efficient Multi-Rotor Wind Turbine System for Decentralized Power"*.
  - Strategic backing through ANRF accelerated research grants, CBDE schemes, and V3F incubation.

### 2. VNIT Department of Electrical Engineering Technical Presentation
- **File Reference**: `Presentation.pdf` / `Presentation.pptx` (Archived in project root)
- **Presenter / Mentor**: Dr. Jawahar Bhukya, Assistant Professor, EEE Department, VNIT Nagpur
- **Key Contents**:
  - Detailed modal and time-domain analysis of Wind Energy Conversion Systems (WECS).
  - Small signal stability analysis, sub-synchronous oscillations (SSO), and DFIG/converter dynamics under grid fault conditions.
  - Comparative analysis of wind generator topologies and converter-driven stability.

### 3. Betz Limit & Classical Momentum Theory Reference
- **File Reference**: `Betz limit.pptx` (Archived in project root)
- **Key Contents**:
  - First-principles mathematical derivation of the Betz limit ($C_{p,\max} = 16/27 = 0.593$) based on 1D axial momentum theory and conservation of mass/energy.
  - Energy path from atmospheric flow to grid interface.

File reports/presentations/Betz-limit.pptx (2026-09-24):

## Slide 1


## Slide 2


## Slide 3


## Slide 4


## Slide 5


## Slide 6


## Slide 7


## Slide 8


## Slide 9

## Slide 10


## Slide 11


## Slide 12


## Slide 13


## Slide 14

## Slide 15


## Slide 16


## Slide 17


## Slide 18

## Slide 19


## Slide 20


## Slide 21

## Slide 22


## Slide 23


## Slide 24

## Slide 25


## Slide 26

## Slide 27


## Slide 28

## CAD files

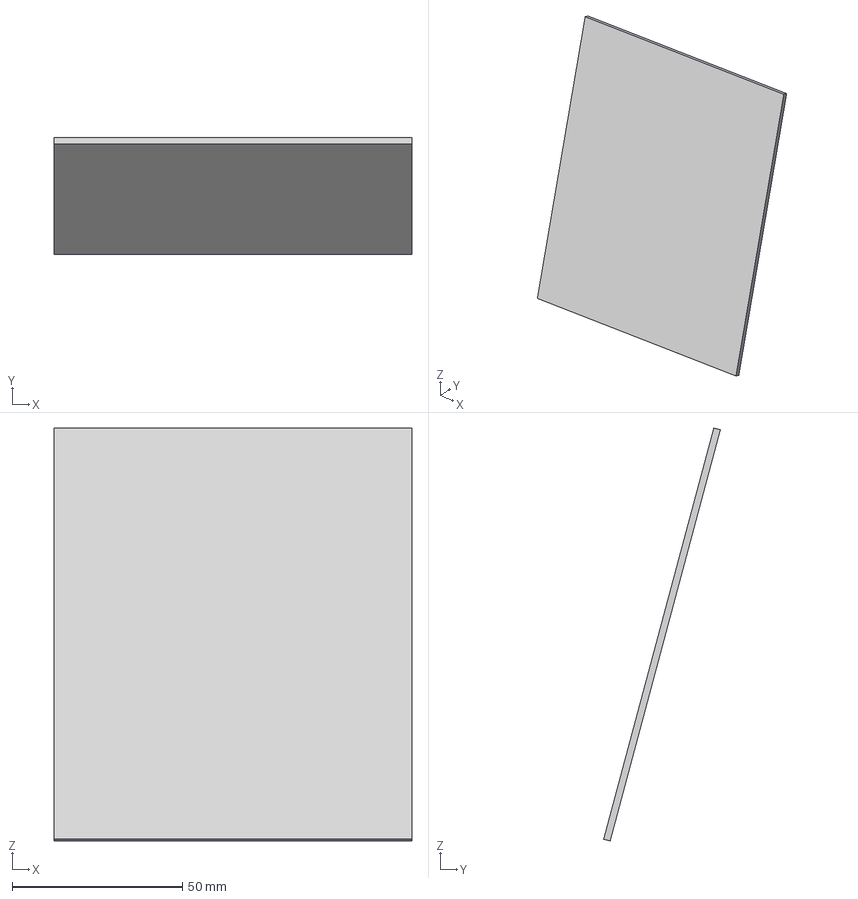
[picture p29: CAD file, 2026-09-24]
engineering/cad/back-plate.step
105.0 x 34.3 x 121.3 mm

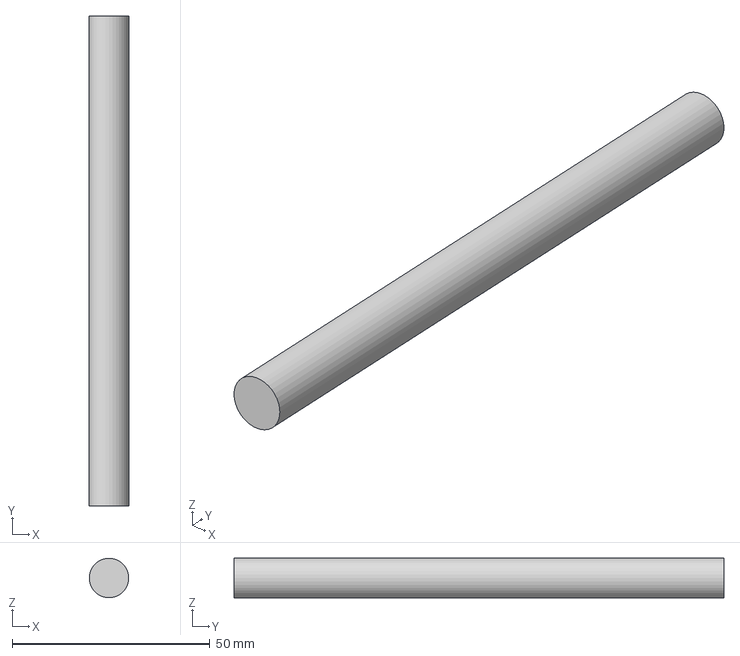
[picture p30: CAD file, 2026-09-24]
engineering/cad/stl-and-3mf/r.3mf
10.0 x 124.0 x 10.0 mm

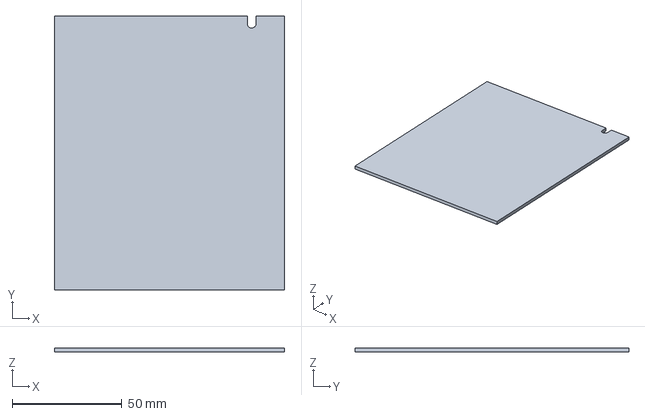
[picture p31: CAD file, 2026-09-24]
engineering/cad/stl-and-3mf/back plate_1.3mf
105.0 x 125.0 x 2.00 mm

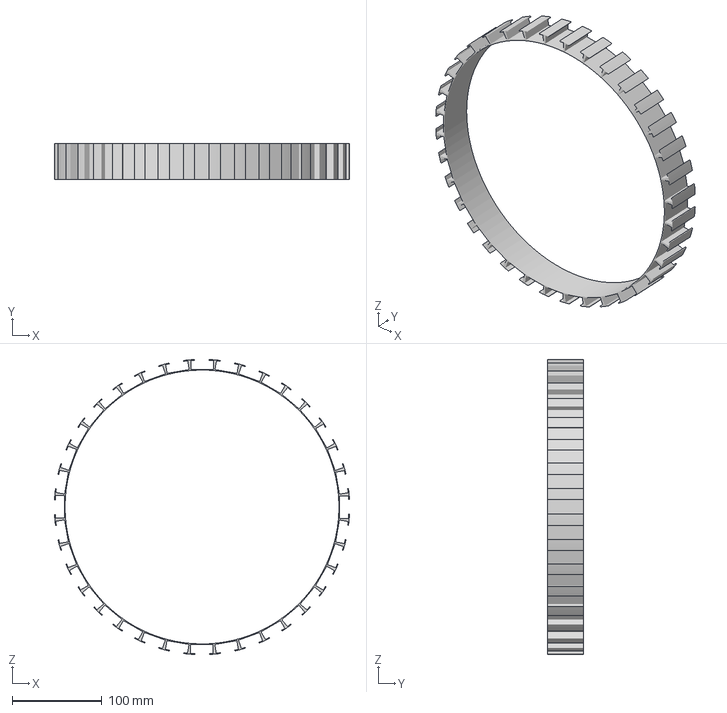
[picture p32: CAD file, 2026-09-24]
engineering/cad/stl-and-3mf/silver strips.3mf
329.6 x 40.0 x 329.6 mm

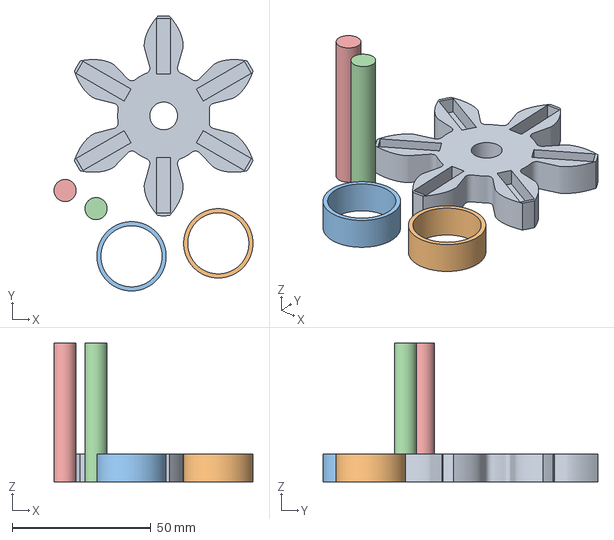
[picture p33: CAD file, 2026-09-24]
engineering/cad/stl-and-3mf/t.3mf
71.7 x 99.1 x 50.0 mm

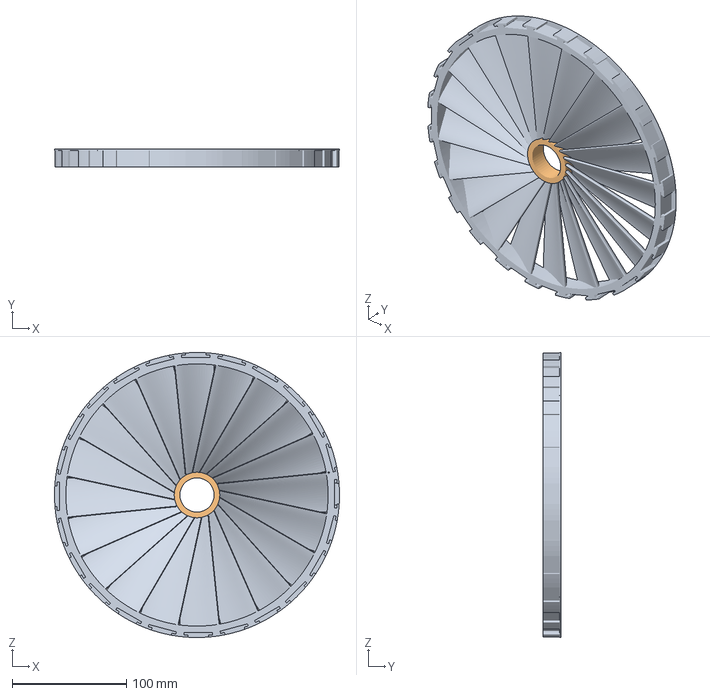
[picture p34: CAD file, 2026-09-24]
engineering/cad/stl-and-3mf/manet 25cm gear.3mf
250.0 x 15.4 x 250.0 mm

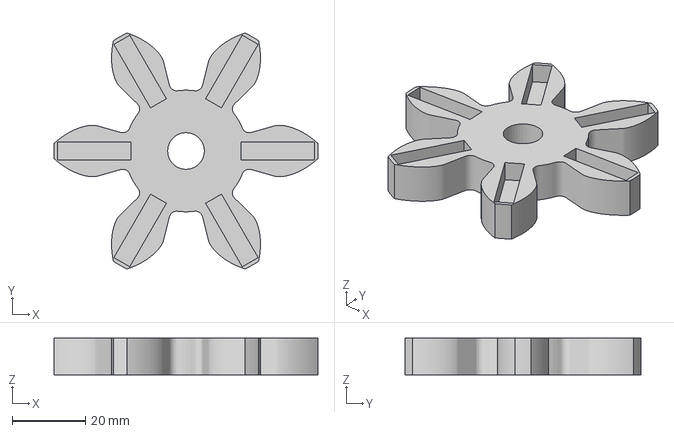
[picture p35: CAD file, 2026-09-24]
engineering/cad/stl-and-3mf/generator gear.3mf
72.0 x 64.4 x 10.0 mm

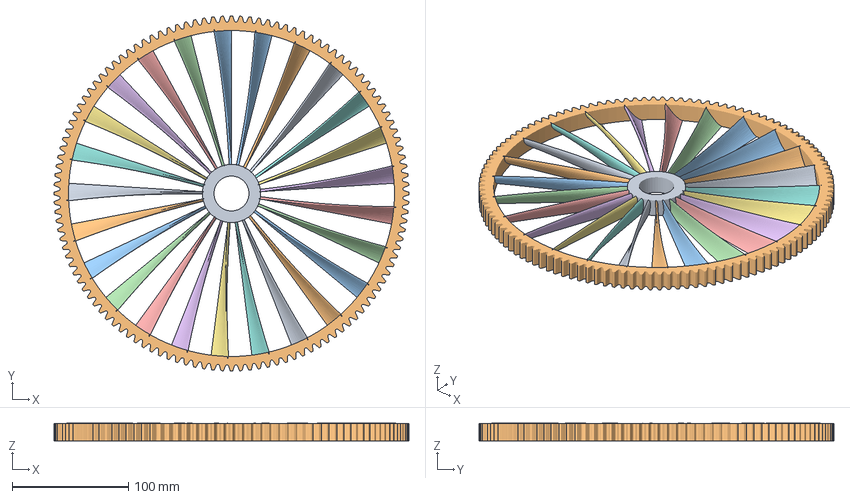
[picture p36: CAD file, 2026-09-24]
engineering/cad/stl-and-3mf/new gear desing_30cm_aniclockwise.3mf
305.0 x 305.0 x 15.1 mm

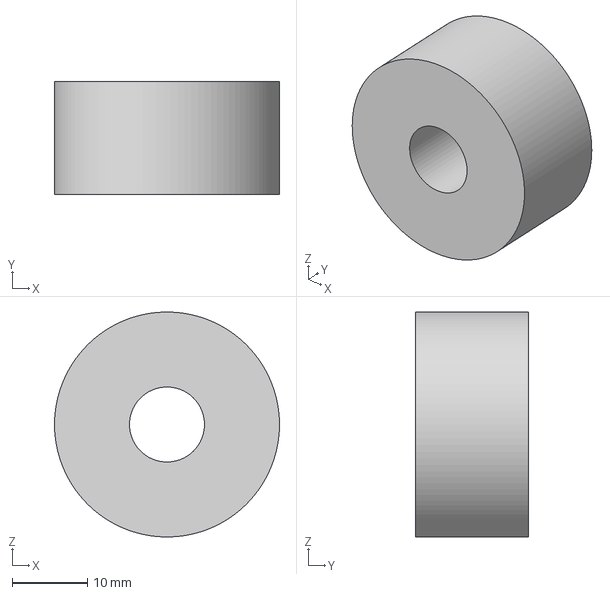
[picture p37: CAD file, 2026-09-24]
engineering/cad/stl-and-3mf/ngi.3mf
30.0 x 15.0 x 30.0 mm

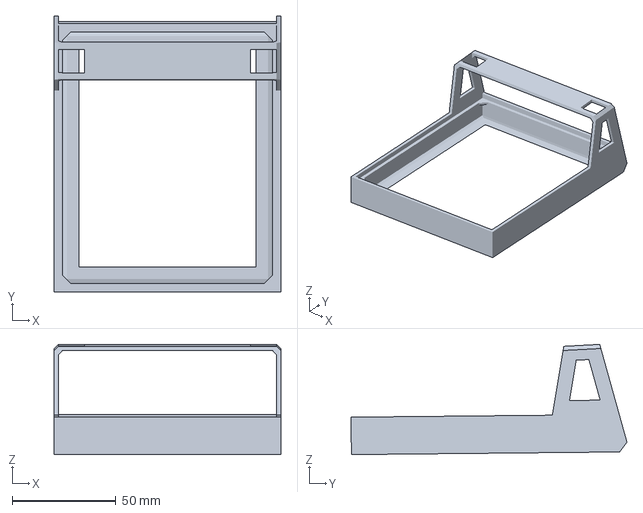
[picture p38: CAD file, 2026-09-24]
engineering/cad/stl-and-3mf/frame_cad.3mf
109.0 x 132.7 x 53.0 mm

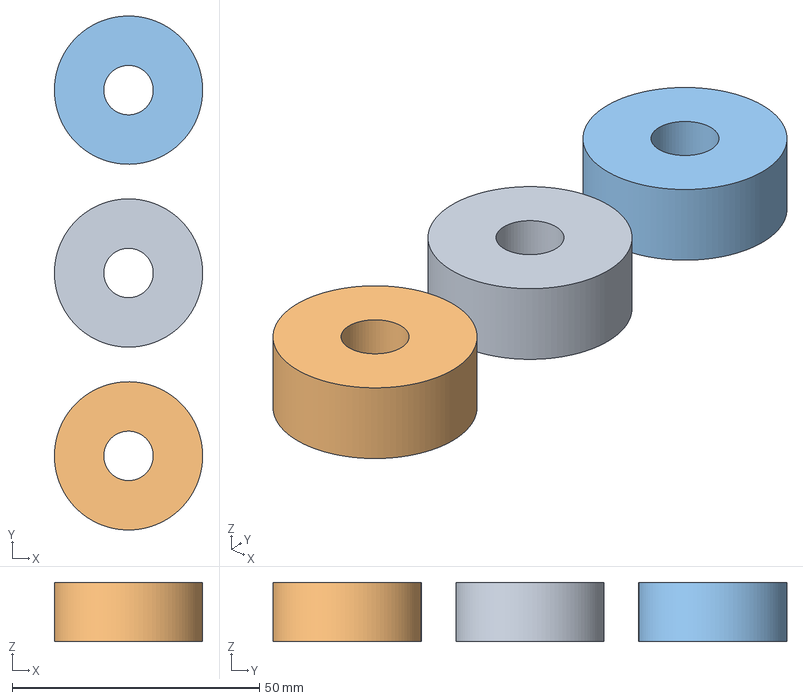
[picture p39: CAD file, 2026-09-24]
engineering/cad/stl-and-3mf/stoper for grear.3mf
30.0 x 104.0 x 12.0 mm

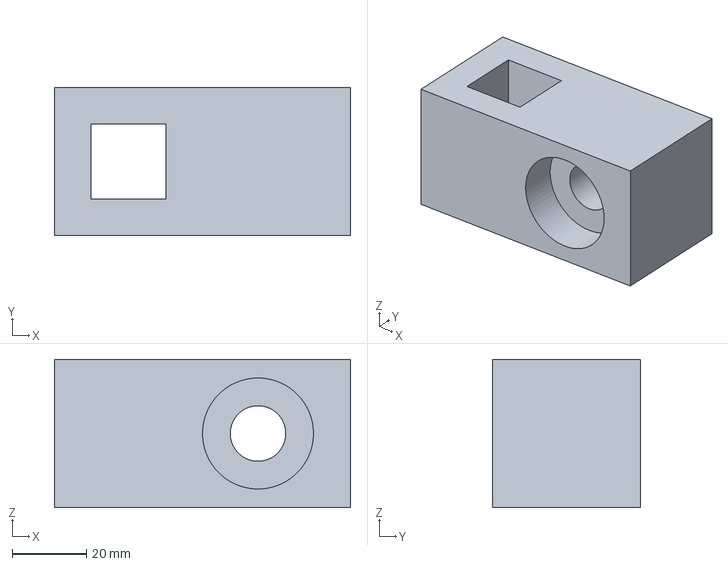
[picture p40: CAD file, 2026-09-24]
engineering/cad/stl-and-3mf/30cm_2.5mod_s1223prof_gear1.3mf
80.0 x 40.0 x 40.0 mm

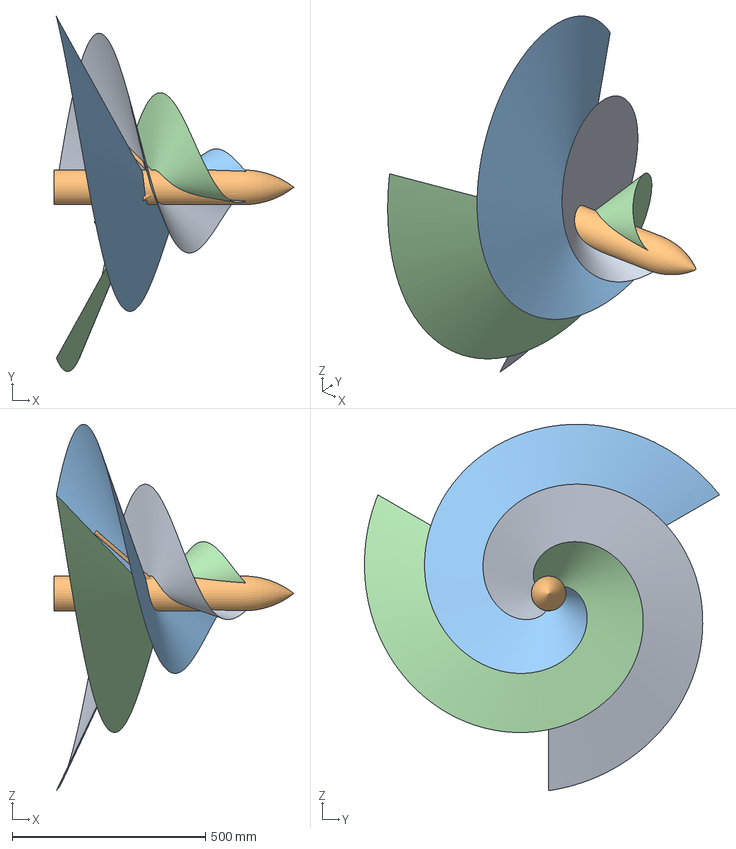
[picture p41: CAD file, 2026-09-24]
engineering/cad/stl-and-3mf/Model-2.3mf
620.0 x 917.9 x 947.4 mm

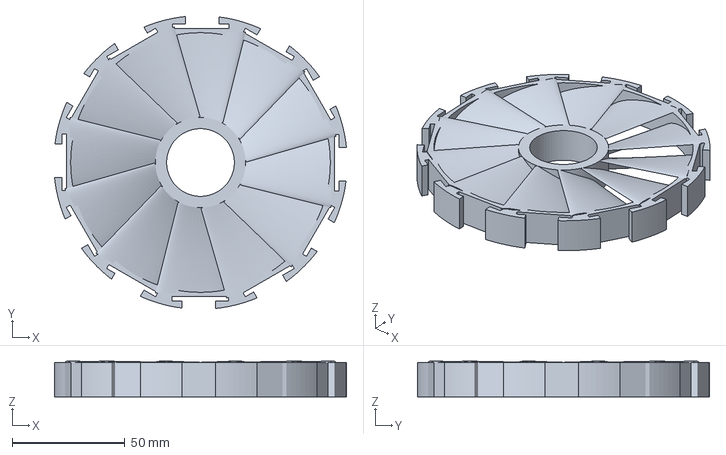
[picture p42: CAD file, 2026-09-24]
engineering/cad/stl-and-3mf/manet 150cm gear acl.3mf
129.3 x 129.3 x 15.9 mm

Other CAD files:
engineering/cad/stl-and-3mf/30cm_2.5mod_s1223prof_gear.3mf
engineering/cad/stl-and-3mf/fan gear.3mf
engineering/cad/stl-and-3mf/frame_cad_1.3mf
engineering/cad/stl-and-3mf/Model-23.3mf
engineering/cad/Model-2.f3d
engineering/cad/Model-23.f3d
engineering/cad/fan-gear.f3d
engineering/cad/ringforferritemagnetsv2.f3d
engineering/cad/stl-and-3mf/Configuration 2.stl
engineering/cad/stl-and-3mf/Untitled.3mf
engineering/cad/stl-and-3mf/a1a2.stl
engineering/cad/stl-and-3mf/back plate.stl
engineering/cad/stl-and-3mf/bkg305.941.3mf
engineering/cad/stl-and-3mf/frame_cad.stl
engineering/cad/stl-and-3mf/magnetic gear.3mf
engineering/cad/stl-and-3mf/ringforferritemagnetsv2.stl
engineering/cad/stl-and-3mf/rt.3mf
engineering/cad/stl-and-3mf/silver strips2.3mf

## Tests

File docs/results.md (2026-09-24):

# Results & Performance Synthesis

This document provides a strictly transparent breakdown of PAWAN SHAKTI performance metrics, separating empirical observations from theoretical calculations, component specifications, design targets, and unvalidated parameters.

---

## 1. Experimentally Measured Data

*Results physically recorded during prototype bench and outdoor evaluations at VNIT Nagpur:*

| Metric | Measured Value | Conditions / Setup |
| :--- | :--- | :--- |
| **Physical Cut-In Wind Speed** | $2.3\text{ to }2.5\text{ m/s}$ | Observed spontaneous rotation and voltage generation on Mark-3 and Mark-4 prototypes. |
| **Mark-3 Output at $4.2\text{ m/s}$** | $26.04\text{ W}$ ($12.4\text{ V}$, $2.1\text{ A}$) | Outdoor ground mast run into $5.9\ \Omega$ load bank. |
| **Mark-4 Output at $4.5\text{ m/s}$** | $36.25\text{ W}$ ($14.5\text{ V}$, $2.5\text{ A}$) | Flow channel testing, 4-rotor synchronized configuration. |
| **No-Load Cut-Off Wind Speed** | $> 8.0\text{ m/s}$ sustained | Evaluated without structural deformation; full high-speed storm survival testing remains to be done. |
| **Operating Rotor RPM** | $180\text{--}400\text{ RPM}$ | Optical tachometer measurement under $2.5\text{--}5.5\text{ m/s}$ airflow. |
| **Generator RPM (Stepped-Up)** | $1,800\text{--}3,600\text{ RPM}$ | Verified across 1:10 transmission ratio. |

---

## 2. Calculated Engineering Values

*Values derived from analytical equations, aerodynamic theory, and computational sizing:*

| Parameter | Calculated Value | Governing Equation & Assumptions |
| :--- | :--- | :--- |
| **Available Wind Power at $4.5\text{ m/s}$** | $52.3\text{ W}$ ($D = 1.0\text{ m}$ cluster) | $P_{\text{wind}} = \frac{1}{2} \rho A V^3$ ($\rho = 1.151\text{ kg/m}^3, A = 0.785\text{ m}^2$). |
| **Theoretical Aerodynamic Limit** | $C_{p,\text{Betz}} = 0.593$ | Albert Betz 1D momentum conservation limit. |
| **Estimated Rotor Aerodynamic Yield** | $C_p \approx 0.40\text{--}0.48$ | Calculated from Selig S1223 2D airfoil polar integration at optimal Tip Speed Ratio ($\lambda \approx 2.5$). |
| **Theoretical Blade Radius for 100W at $4.5\text{ m/s}$**| $r \approx 1.13\text{ m}$ ($D \approx 2.26\text{ m}$) | Direct equation solving: $100\text{ W} = 0.5 \times 0.48 \times 1.151 \times \pi r^2 \times (4.5)^3$. |
| **Scaled Single-Rotor Equivalent Area**| $A \approx 4.0\text{ m}^2$ | Required single rotor area to produce continuous 100W at $4.5\text{ m/s}$ without multi-rotor aggregation. |
| **DFIG Stator / Rotor Split (Scaled)** | $77\text{ W}$ stator / $23\text{ W}$ rotor | DFIG slip power partitioning at $s = -0.3$ slip condition. |

---

## 3. Design Specifications

*Hardware specifications determined from design modeling and manufacturer datasheets:*

| Specification | Parameter | Details |
| :--- | :--- | :--- |
| **Rotor Unit Diameter** | $300\text{ mm}$ ($0.3\text{ m}$) | Dimension of individual modular Selig S1223 turbine unit. |
| **Transmission Architecture** | Coaxial Planetary Gearbox | 1:10 speed step-up ratio; $20^\circ$ pressure angle; module 2.5 spur gear teeth. |
| **Generator Rating** | $100\text{ W}$ continuous DC | Nominal $24\text{ V DC}$, rated current $4.16\text{ A}$ (tested alongside $110\text{ V}$, $3500\text{ RPM}$ unit). |
| **Generator Conversion Efficiency** | $80\text{--}85\%$ | Manufacturer rated electromechanical conversion efficiency at nominal speed. |
| **Frame Material** | 6063-T6 Aluminum / Steel | Modular slotted extrusion frame with waterjet aluminum backing plates. |
| **Blade Material** | FDM 3D-Printed ABS | $1.04\text{ g/cm}^3$ density, high infill at root hub, UV protective coating. |

---

## 4. Engineering Targets

*Performance objectives that the project actively aims to achieve through ongoing refinement:*

- **Target Cut-In Wind Speed**: $\le 2.0\text{ m/s}$ through low-friction ceramic bearings and magnetic gearing.
- **Rated Power Threshold**: $100\text{ W}$ electrical output sustained at $5.5\text{ m/s}$.
- **Unit Manufacturing Cost Target**: $\approx ₹35,000$ for mass-production modular package.
- **Operational Wind Range**: $2.0\text{ to }20.0\text{ m/s}$ with passive mechanical furling or electrical dump-load braking.

---

## 5. Parameters Not Yet Validated / Open Research Gaps

> [!WARNING]
> The following parameters require further empirical research before definitive claims can be made:

1. **Overall End-to-End System Efficiency**: While generator electrical efficiency is rated at $80\text{--}85\%$ and aerodynamic $C_p$ is modeled at $0.40\text{--}0.48$, true end-to-end efficiency across the combined aerodynamic-mechanical-electrical chain across full wind curves requires formal dynamometer wind tunnel calibration.
2. **Long-Term Outdoor Durability (FDM Polymers)**: Degradation of 3D-printed ABS gear teeth under continuous atmospheric exposure (solar UV radiation, thermal expansion, dust abrasion) requires 6-month continuous field testing.
3. **Multi-Rotor Aerodynamic Interference**: Wake interaction and mutual boundary-layer interference between closely clustered rotors in the 4-rotor and 5-rotor configurations require formal Particle Image Velocimetry (PIV) or high-fidelity 3D CFD analysis.
4. **Economic Payback & O&M Cost**: The projected 7–8 year payback period and ₹2,000–₹5,000/year maintenance figures represent preliminary economic modeling and must be confirmed through multi-site pilot trial data.

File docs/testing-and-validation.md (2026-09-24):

# Testing & Experimental Validation

## 1. Experimental Methodology & Test Architecture

To validate the PAWAN SHAKTI system under real physical operating conditions, a structured multi-parameter sensor acquisition setup was developed based on an **ESP32 microcontroller gateway**.

```
+-----------------------------------------------------------------------------------+
|                        EXPERIMENTAL SENSOR INTEGRATION PIPELINE                   |
|                                                                                   |
|  [ Physical Parameter ]          [ Transducer / Sensor ]        [ ESP32 Logger ]  |
|  - Wind Velocity (m/s)  -------> Cup Anemometer (Pulse / Int)  --> GPIO Interrupt |
|  - Rotor / Gen Speed    -------> Optical Tachometer (Pulse)    --> GPIO Counter   |
|  - System Voltage (V)   -------> Calibrated Resistor Divider   --> ADC Pin (12-bit|
|  - Load Current (A)     -------> Hall-Effect Sensor (ACS712)   --> ADC Pin        |
|  - Structural Vibration -------> 3-Axis Accelerometer (ADXL345)--> I2C Bus        |
|                                                                        |          |
|                                                                        v          |
|                                                                 [ Time-Stamped    |
|                                                                   CSV Data Log ]  |
+-----------------------------------------------------------------------------------+
```

---

## 2. Documented Test Logs & Empirical Benchmarks

The following test records document prototype characterization across outdoor bench runs and wind tunnel evaluations at VNIT Nagpur:

### Test Log 01: Mark-3 (3-Rotor Clustered Prototype - Config A)
- **Test ID**: `EXP-M3-001`
- **Date**: 29 July 2026
- **Location**: VNIT Campus outdoor testing site, Nagpur
- **Objective**: Measure electromechanical output and cut-in behavior across natural wind fluctuations.
- **Instrumentation**: Fluke Digital Multimeter, ESP32 datalogger, optical tachometer, cup anemometer.
- **Connected Load**: $5.9\ \Omega$ resistive power resistor load bank.

| Timestamp | Config | Wind Speed ($V_w$) | Rotor RPM | Gen Voltage ($V$) | Load Current ($I$) | Electrical Power ($P$) | Observations / Status |
| :---: | :---: | :---: | :---: | :---: | :---: | :---: | :--- |
| `09:00:01` | Config A (3-Rotor) | $4.2\text{ m/s}$ | $310\text{ RPM}$ | $12.4\text{ V}$ | $2.10\text{ A}$ | $26.04\text{ W}$ | Stable rotation; steady meshing. |
| `09:15:22` | Config A (3-Rotor) | $2.4\text{ m/s}$ | $185\text{ RPM}$ | $7.2\text{ V}$ | $0.85\text{ A}$ | $6.12\text{ W}$ | Approaching cut-in boundary. |
| `09:30:10` | Config A (3-Rotor) | $1.9\text{ m/s}$ | $0\text{ RPM}$ | $0.0\text{ V}$ | $0.00\text{ A}$ | $0.00\text{ W}$ | Stalled below static cut-in threshold. |
| `10:05:44` | Config A (3-Rotor) | $3.5\text{ m/s}$ | $265\text{ RPM}$ | $10.6\text{ V}$ | $1.65\text{ A}$ | $17.49\text{ W}$ | Smooth re-acceleration after gust. |
| `10:45:18` | Config A (3-Rotor) | $5.1\text{ m/s}$ | $390\text{ RPM}$ | $15.8\text{ V}$ | $2.80\text{ A}$ | $44.24\text{ W}$ | Strong output; minor high-frequency gear mesh vibration. |

- **Empirical Cut-in Observed**: $2.3\text{--}2.5\text{ m/s}$
- **Key Learning**: Clustered 3-rotor layout starts reliably once wind exceeds $2.3\text{ m/s}$, but gear mesh friction prevents rotation below $2.0\text{ m/s}$.

---

### Test Log 02: Mark-4 (4-Rotor Planar Matrix - Config B)
- **Test ID**: `EXP-M4-002`
- **Date**: 18 August 2026
- **Location**: Aerodynamics Lab / Subsonic Flow Channel, VNIT Nagpur
- **Objective**: Comparative starting torque and multi-rotor speed synchronization under controlled flow.
- **Instrumentation**: Bench flow anemometer, digital optical tachometer, regulated electronic DC load.

| Flow Speed ($V_w$) | Cluster RPM | Gen Output Voltage | Current ($I$) | Power Output | Relative Performance vs. Config A |
| :---: | :---: | :---: | :---: | :---: | :--- |
| $2.5\text{ m/s}$ | $195\text{ RPM}$ | $7.8\text{ V}$ | $0.95\text{ A}$ | $7.41\text{ W}$ | $+21\%$ power at low speed due to higher torque solidity. |
| $3.5\text{ m/s}$ | $285\text{ RPM}$ | $11.4\text{ V}$ | $1.85\text{ A}$ | $21.09\text{ W}$ | $+20.5\%$ power over 3-rotor cluster. |
| $4.5\text{ m/s}$ | $360\text{ RPM}$ | $14.5\text{ V}$ | $2.50\text{ A}$ | $36.25\text{ W}$ | Higher total swept area increases captured kinetic energy. |

- **Observations**: 4-rotor configuration provides higher starting torque and earlier cut-in reliability, but mechanical alignment between 4 meshing pinions requires stricter shaft tolerance.

---

### Test Log 03: Mark-5 (5-Rotor KECS Prototype - Config C)
- **Test ID**: `EXP-M5-003`
- **Date**: 12 September 2026
- **Location**: Workshop Test Rig, VNIT Nagpur
- **Objective**: Full electromechanical transmission test of 5-rotor array coupled to central spur transmission on aluminum extrusion chassis.
- **Observations**: The large swept area provided substantial aerodynamic torque, but accumulated backlash and friction across 5 simultaneous meshing interfaces created excessive drag.
- **Result**: Proved that simply increasing the number of mechanically geared rotors has diminishing returns due to compounding gear friction. Directly motivated the shift toward **contactless magnetic gear couplings** to eliminate multi-gear tooth friction.

---

## 3. Machine Learning Baseline Model Scope

As outlined in [`testing/test-protocols/ESP32-Sensor-Logging-Protocol.md`](../testing/test-protocols/ESP32-Sensor-Logging-Protocol.md), an end-to-end data processing and regression model pipeline was created:
- **Inputs**: $V_w$ (Wind Speed), Rotor RPM, Generator Voltage ($V$), Current ($I$), Vibration ($X, Y, Z$), Config ID.
- **Target Variable**: Electrical Power ($P = V \times I$).
- **Baseline Models**: Multi-variable Linear Regression, followed by Random Forest regressor (80/20 train/test split).
- **Objective**: Establish baseline power curve estimation and predictive anomaly detection for field deployment.

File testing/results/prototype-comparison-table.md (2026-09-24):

# Prototype Comparative Benchmarks (Configurations A, B, C)

This benchmark compiles the experimental observations across the three developed prototype configurations of PAWAN SHAKTI.

---

## Configuration Matrix Summary

| Parameter | Configuration A (Mark-3) | Configuration B (Mark-4) | Configuration C (Mark-5 / KECS) |
| :--- | :--- | :--- | :--- |
| **Aero Architecture** | 3-Rotor Clustered Array | 4-Rotor Planar Matrix | 5-Rotor Star/Central Array |
| **Rotor Diameter (Each)** | $300\text{ mm}$ ($0.3\text{ m}$) | $300\text{ mm}$ ($0.3\text{ m}$) | $300\text{ mm}$ ($0.3\text{ m}$) |
| **Total Effective Swept Area**| $\approx 0.21\text{ m}^2$ | $\approx 0.28\text{ m}^2$ | $\approx 0.35\text{ m}^2$ |
| **Airfoil Profile** | Selig S1223 high-lift | Selig S1223 high-lift | Selig S1223 high-lift |
| **Transmission Arrangement** | Coaxial Planetary Gearbox | Coaxial Planetary / Spur | Multi-pinion spur cluster |
| **Step-Up Ratio** | 1:10 | 1:10 | 1:10 |
| **Observed Cut-In Velocity** | **$2.3\text{--}2.5\text{ m/s}$** | **$2.4\text{--}2.6\text{ m/s}$** | **$2.8\text{--}3.2\text{ m/s}$** (Higher starting friction) |
| **Measured Power at $3.5\text{ m/s}$** | $17.49\text{ W}$ | $21.09\text{ W}$ ($+20.5\%$) | $9.79\text{ W}$ (Degraded by gear drag) |
| **Measured Power at $4.5\text{ m/s}$** | $31.2\text{ W}$ (interpolated) | $36.25\text{ W}$ | $24.8\text{ W}$ |
| **Mechanical Complexity** | Low-Medium (single carrier) | Medium (dual-stage linkage)| High (5 meshing interfaces) |
| **Acoustic Noise / Vibration** | Minimal ($< 45\text{ dB}$) | Moderate ($< 52\text{ dB}$) | Noticeable tooth rattling ($> 60\text{ dB}$) |
| **Overall Assessment** | **Clean baseline prototype** | **Highest empirical efficiency**| **Excessive mechanical loss**; proves limit of mechanical gearing |

---

## Key Experimental Findings

1. **Torque Solidity vs. Swept Area**:
   Transitioning from 3 rotors (Config A) to 4 rotors (Config B) provided a $33\%$ increase in physical swept area and yielded a proportional $+20\text{--}21\%$ gain in electrical power output while maintaining an early cut-in speed ($2.4\text{ m/s}$).
2. **The Frictional Drag Ceiling in Config C**:
   Expanding to 5 rotors in Config C increased frontal area, but the accumulation of tooth contact friction across 5 separate meshing pinions raised the cut-in wind speed to $\approx 3.0\text{ m/s}$ and dissipated substantial kinetic energy as friction and heat.
3. **Engineering Decision**:
   Configuration B represents the optimal physical layout for multi-rotor harvesting. Future iterations will replace the physical spur teeth in Config B with **contactless magnetic gears** to decouple rotor clustering from mechanical friction penalties.

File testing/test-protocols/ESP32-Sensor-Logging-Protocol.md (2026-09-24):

# ESP32 Sensor Logging & Rotation Protocol

## 1. Objective

Standardize the empirical data collection pipeline across all physical turbine configurations (Configuration A: 3-Rotor, Configuration B: 4-Rotor, Configuration C: 5-Rotor) to ensure rigorous, time-synchronized, and unbiased comparative analysis.

---

## 2. Hardware Instrumentation Setup

```
   [ Cup Anemometer ]  ---------> GPIO 14 (Interrupt Pin / Falling Edge)
   [ Optical Tachometer ] ------> GPIO 13 (Pulse Counter)
   [ DC Bus Voltage (0–30V) ] --> Resistor Divider (100k / 10k) --> ADC GPIO 34 (12-bit)
   [ DC Bus Current (0–10A) ] --> ACS712-20A Hall Sensor ------> ADC GPIO 35 (12-bit)
   [ ADXL345 Vibration ] -------> I2C (SDA: GPIO 21, SCL: GPIO 22)
```

### Critical Rules:
1. **Synchronous Sampling**: Wind speed MUST be logged in the exact same timestamp row as voltage, current, RPM, and vibration. Asynchronous weather station logs are prohibited.
2. **Rotation Protocol**: To prevent atmospheric bias (e.g., testing one configuration during a morning gust and another during midday calm), configurations MUST be rotated sequentially every 2 to 3 hours across the test day:
   $$\text{Config A} \longrightarrow \text{Config B} \longrightarrow \text{Config C} \longrightarrow \text{Config A}$$
3. **Data Integrity**: Raw sensor values must never be manually altered or retroactively smoothed. Outliers, cable disconnects, or manual configuration shifts must be annotated in the `Notes` field.

---

## 3. Data Schema & Logging Format

All test logs are output in comma-separated values (CSV) with the following schema:

| Column Header | Data Type | Engineering Units | Description |
| :--- | :--- | :--- | :--- |
| `Timestamp` | ISO 8601 String | `YYYY-MM-DD HH:MM:SS` | Real-time clock (RTC) synchronized timestamp. |
| `Config_ID` | Categorical String | `A`, `B`, or `C` | Configuration designation (`A`=3-rotor, `B`=4-rotor, `C`=5-rotor). |
| `Voltage_V` | Floating Point | Volts ($\text{V}$) | DC generator terminal voltage. |
| `Current_A` | Floating Point | Amperes ($\text{A}$) | Load circuit current. |
| `Power_W` | Floating Point | Watts ($\text{W}$) | Calculated electrical power ($P = V \times I$). |
| `Rotor_RPM` | Floating Point | Revolutions per minute | Measured rotational speed of primary aerodynamic rotor. |
| `Wind_Speed_ms` | Floating Point | Meters per second ($\text{m/s}$) | Freestream velocity from cup anemometer at rotor centerline height. |
| `Wind_Direction` | String | Compass Cardinal / Degrees | Ambient wind direction (e.g., `NE`, `SW`). |
| `Vib_XYZ_g` | String | $g$-force ($\text{m/s}^2$) | Triaxial vibration vector (`X/Y/Z`). |
| `Notes` | Text String | Free text | Annotations: gusts, load step changes, calibration events. |

---

## 4. Machine Learning Baseline Model Architecture

The sensor stream feeds directly into an automated Python preprocessing and regression pipeline:
1. **Data Cleaning**: Discard startup transient rows ($V < 0.1\text{ V}$, $RPM = 0$) and detect sensor dropout anomalies.
2. **Feature Matrix**: $[V_{\text{wind}}, \text{RPM}, \text{Config\_ID (one-hot)}, \text{Vib\_Magnitude}]$.
3. **Target**: Electrical Power ($P_{\text{elec}}$).
4. **Model Comparison**:
   - Baseline: Ordinary Least Squares (OLS) Linear Regression ($R^2$ baseline).
   - Non-linear: Random Forest Regressor and Gradient Boosted Trees (XGBoost).
   - Split: $80\%$ Training / $20\%$ Validation.

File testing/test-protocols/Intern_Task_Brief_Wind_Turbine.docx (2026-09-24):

Wind Turbine Data Collection — Intern Task Brief

Duration: 2 Days | Project: Yashvant Turbine — Smart Optimization System

# Goal

Collect a clean, well-labeled sensor dataset from all three turbine configurations, across a range of wind conditions, and use it to train a working baseline power-prediction model. By the end of Day 2, we need a spreadsheet of continuous, time-stamped readings — with wind speed included — plus a first-pass trained model with reported accuracy, ready to be improved with more data later.

# What We Already Have

- ESP32 gateway set up to log sensor data (to Excel/Sheet or via serial)
- Sensors: Voltage (V), Current (A), RPM, Vibration (X, Y, Z — if available), Wind Direction
- Three turbine configurations to test (Config A, B, C)

# What's New / Must Be Added

Wind speed is the most important missing parameter. Without it, we cannot fairly compare the three configurations — a config may look better simply because it was tested on a windier day. Wind speed must be logged at the same time and frequency as every other sensor reading.

- Add a cup anemometer (pulse/reed switch type) wired to an ESP32 interrupt pin — cheapest and easiest option.
- If a Davis/NRG anemometer is available, that also works (analog or pulse output).
- Log wind speed in the same row/timestamp as V, I, RPM, vibration, and direction — never as a separate slower log.

# Day 1 — Hardware Setup & Test Run

## Morning

☐ Wire up anemometer to ESP32 (interrupt pin for pulse counting)

☐ Write/update firmware to read wind speed alongside existing sensors

☐ Confirm all sensors report correctly together: V, I, RPM, Vibration X/Y/Z, Wind Speed, Wind Direction

## Afternoon

☐ Set up logging destination (Excel via Sheets webhook, or local CSV/SD card on ESP32)

☐ Create the column structure (see table below) in the logging sheet

☐ Run a 30–60 minute test log on ONE configuration to confirm data looks correct (no missing values, timestamps consistent, power calculates correctly)

☐ Fix any issues found during the test run before scaling up

# Day 2 — Data Collection + Baseline AI Model

## Morning — Continue Data Collection

☐ Start continuous logging on Configuration A

☐ Rotate through all 3 configurations across the day (e.g., A → B → C → A...) every 2–3 hours, so each config sees a similar mix of wind conditions — don't run one config only when it's windy and another only when it's calm

## Afternoon — Continue Rotation

☐ Continue rotation, aim for at least 2–3 hours of logged data per configuration

☐ Spot-check the sheet every hour: no gaps, no stuck sensor values, timestamps updating

## End of Day 2 — Clean Data + Train a Baseline Model

☐ Export/clean the final spreadsheet (remove test-run data from Day 1)

☐ Add a short notes column entry for anything unusual (e.g., 'gust,' 'sensor reset,' 'manual config change at 3:15pm')

☐ Load cleaned data into Python (pandas) — drop rows with missing/stuck sensor values

☐ Confirm Power = V × I is calculated; add simple extra features if time allows (e.g., rolling avg wind speed)

☐ Train a simple baseline model (Linear Regression, then Random Forest or XGBoost) to predict Power from V, I, RPM, Wind Speed, Wind Direction, Vibration, Config ID

☐ Do an 80/20 train/test split and report accuracy (R², MAE, or RMSE) — a working first pass, not the final model

☐ Save the trained model file (.pkl or .joblib) and the script used to train it

☐ Hand off: completed sheet, cleaning/training script, model file, accuracy numbers, and a 2–3 line summary of what was observed per configuration

# AI Training Scope (Day 2, Baseline Only)

This is a first-pass baseline model, not the full production system. The goal is to prove the pipeline works end-to-end — raw data → cleaned data → trained model → accuracy metric — using whatever is collected in this 2-day window. It gets retrained later once more data exists.

- Clean & preprocess: handle missing values, remove obvious sensor glitches (e.g., impossible RPM spikes).
- Feature engineering: Power (already calculated), Config ID as a categorical feature, optional rolling averages for wind speed/vibration.
- Model: start with Linear Regression, then try one tree-based model (Random Forest or XGBoost) and compare.
- Target variable: Power (W). Stretch goal if time allows: flag which Config ID gave highest power for similar wind speed.
- Report accuracy honestly — with only ~1 day of real data, don't expect high accuracy yet. The goal is a working pipeline, not a polished model.

# Required Data Columns

Timestamp | Config ID | Voltage (V) | Current (A) | Power (W) | RPM | Wind Speed (m/s) | Wind Dir. | Vib X/Y/Z
2026-07-29 09:00:01 | A | 12.4 | 2.1 | =V×I | 310 | 4.2 | NE | 0.02/0.01/0.03

Add a Notes column at the end for anything unusual observed during logging (gusts, manual changes, sensor resets).

# Rules for Good Data

- Log every reading with a real timestamp — never leave timestamp blank or estimated.
- Rotate configurations regularly (don't leave one config running all day) so wind conditions are shared fairly across all three.
- Don't edit/delete raw values after the fact — if something looks wrong, add a note instead of fixing the number.
- Keep sampling rate consistent (e.g., once every few seconds) — irregular gaps make the data harder to use.

# Deliverable (End of Day 2)

One spreadsheet (Excel or CSV) with continuous, rotated, timestamped data across all 3 configurations, wind speed included — plus a trained baseline model (script + model file + accuracy metrics) and a short written note on anything unusual observed.

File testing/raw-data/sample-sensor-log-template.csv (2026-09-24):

Timestamp | Config_ID | Voltage_V | Current_A | Power_W | Rotor_RPM | Wind_Speed_ms | Wind_Direction | Vib_XYZ_g | Notes
2026-07-29 09:00:01 | A | 12.4 | 2.10 | 26.04 | 310 | 4.2 | NE | 0.02/0.01/0.03 | Steady morning breeze; resistive load 5.9 ohm
2026-07-29 09:00:15 | A | 12.6 | 2.13 | 26.84 | 315 | 4.3 | NE | 0.02/0.01/0.03 | Nominal tracking
2026-07-29 09:00:30 | A | 11.8 | 2.00 | 23.60 | 295 | 3.9 | NE | 0.02/0.01/0.03 | Minor wind drop
2026-07-29 09:15:22 | A | 7.2 | 0.85 | 6.12 | 185 | 2.4 | NNE | 0.01/0.01/0.02 | Approaching cut-in boundary
2026-07-29 09:30:10 | A | 0.0 | 0.00 | 0.00 | 0 | 1.9 | NNE | 0.00/0.00/0.01 | Stalled below static starting threshold
2026-07-29 10:05:44 | A | 10.6 | 1.65 | 17.49 | 265 | 3.5 | NE | 0.02/0.01/0.02 | Re-acceleration after gust
2026-07-29 10:45:18 | A | 15.8 | 2.80 | 44.24 | 390 | 5.1 | ENE | 0.04/0.03/0.05 | Strong gust; peak load test
2026-07-29 11:30:00 | B | 7.8 | 0.95 | 7.41 | 195 | 2.5 | ENE | 0.02/0.02/0.03 | Rotated to Config B (4-Rotor); cut-in active
2026-07-29 11:45:12 | B | 11.4 | 1.85 | 21.09 | 285 | 3.5 | E | 0.02/0.02/0.03 | Config B stable synchronization
2026-07-29 12:00:30 | B | 14.5 | 2.50 | 36.25 | 360 | 4.5 | E | 0.03/0.03/0.04 | Config B higher torque observed
2026-07-29 14:00:10 | C | 5.1 | 0.50 | 2.55 | 140 | 2.8 | E | 0.05/0.04/0.06 | Rotated to Config C (5-Rotor); high mesh drag
2026-07-29 14:15:45 | C | 8.9 | 1.10 | 9.79 | 210 | 3.6 | ESE | 0.06/0.05/0.07 | Config C meshing friction audible

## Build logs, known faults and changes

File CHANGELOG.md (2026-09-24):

# Changelog: PAWAN SHAKTI Development History

All notable technical updates, hardware revisions, and architectural milestones of the PAWAN SHAKTI project are recorded in this document.

---

## [Unreleased] - 2026-Q4 / 2027

### Planned Work
- Wind tunnel dynamometer calibration of Mark-4 with calibrated torque cell.
- Transition of planetary gear train from 3D-printed ABS to CNC-machined POM (Delrin).
- Fabrication of full-scale contactless magnetic gear coupling test rig.
- Implementation of dedicated 24V synchronous buck-boost MPPT microcontroller firmware.

---

## [Mark-5 / Project KECS] - September 2026

### Added
- 5-rotor star/central planar matrix test fixture mounted on modular 6063 aluminum extrusion chassis.
- Pre-incubation agreement executed with VNIT Ventures Vault Foundation (V3F) on 21–23 September 2026.
- Exploratory CAD models for permanent magnet gear rings ([`engineering/cad/ringforferritemagnetsv2.f3d`](engineering/cad/ringforferritemagnetsv2.f3d)).

### Findings
- The 5-rotor mechanical arrangement demonstrated that compounding tooth mesh friction across 5 simultaneous pinions elevates cut-in threshold ($> 3.0\text{ m/s}$), establishing the practical physical limit of multi-rotor spur gearing.

---

## [Mark-4] - August 2026

### Added
- 4-rotor square planar matrix prototype tested in VNIT flow channel.
- ESP32 automated multi-sensor acquisition gateway for synchronized wind speed, RPM, voltage, and current logging.

### Results
- Measured $36.25\text{ W}$ at $4.5\text{ m/s}$ wind velocity.
- Demonstrated superior torque solidity and lowest cut-in wind speed ($2.4\text{ m/s}$) among multi-rotor configurations.

---

## [Mark-3] - Early 2025 – Mid 2026

### Added
- First physical working prototype featuring 3 clustered rotors with integrated module 2.5 spur gear teeth.
- Integrated 1:10 coaxial planetary gearbox coupled to a 100 W DC generator.
- Outdoor test mast characterization with digital multimeter instrumentation.

### Intellectual Property
- Indian Patent application published: *"Compact Wind Turbine with Planetary Gears"* (2025).

---

## [Initial Architecture & Modeling] - 2023 – 2024

### Added
- Aerodynamic selection of the Selig S1223 high-camber profile for low Reynolds number flow ($Re < 100,000$).
- Autodesk Fusion 360 parametric 3D models and 2D engineering drawings (`drawings1.pdf`, `drawings 2.pdf`).
- FEA structural stress and modal analysis in ANSYS.
- Electrical bus scaling calculations comparing 24V vs. 240V DC links.

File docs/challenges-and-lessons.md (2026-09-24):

# Engineering Challenges & Practical Lessons Learned

Authentic engineering research is characterized by confronting physical constraints, debugging mechanical failures, and systematically refining designs. This document details the genuine technical challenges encountered during the design, fabrication, and testing of the PAWAN SHAKTI prototypes.

---

## Challenge 01: Low Aerodynamic Starting Torque vs. Transmission Stiction

```
[ Problem ]
   The initial prototype failed to begin rotating in wind speeds below 3.5 m/s, despite CFD
   calculations indicating positive aerodynamic lift at 2.0 m/s.
      |
      v
[ Investigation ]
   Static torque measurement revealed that the combined breakaway torque of the 1:10 planetary
   gearbox, generator cogging, and deep-groove rubber seals exceeded the static aerodynamic
   torque generated by stationary blades.
      |
      v
[ Modification ]
   1. Transitioned rotor blade profile to the ultra-high-camber Selig S1223 airfoil.
   2. Increased blade solidity (multi-blade impellers).
   3. Removed heavy grease from prototype bearings, replacing it with low-viscosity synthetic lubricant.
      |
      v
[ Result ]
   Spontaneous aerodynamic cut-in wind speed dropped from > 3.5 m/s down to 2.3–2.5 m/s on the test bench.
      |
      v
[ Key Learning ]
   Static breakaway torque (stiction) is the single greatest bottleneck for low-wind micro-turbines.
   Aerodynamic design must optimize static starting torque coefficient (C_Ts), not merely peak dynamic power coefficient (C_p).
      |
      v
[ Next Engineering Step ]
   Implement low-cogging coreless ironless axial-flux generators and evaluate magnetic contactless gearing.
```

---

## Challenge 02: Additive Manufacturing (FDM) Tolerances & Gear Mesh Friction

```
[ Problem ]
   3D-printed ABS planetary and spur gear teeth exhibited noticeable mechanical binding, high
   frictional heating, and acoustic rattling at rotational speeds exceeding 300 RPM.
      |
      v
[ Investigation ]
   FDM 3D printing introduces surface roughness (layer stairstepping Ra ~ 15–20 µm) and localized
   dimensional expansion (+0.15 mm tooth thickness error), causing zero-backlash tight meshing
   and pitch-line binding.
      |
      v
[ Modification ]
   1. Redesigned tooth profiles in Fusion 360 with deliberate 0.25 mm tooth flank backlash clearance.
   2. Switched from standard module 1.5 to module 2.5 spur teeth for greater tooth bending strength.
   3. Tested post-processing vapor smoothing on ABS components and applied PTFE dry-film lubricant.
      |
      v
[ Result ]
   Gearbox mechanical transmission efficiency improved significantly; binding was eliminated up to 600 RPM.
      |
      v
[ Key Learning ]
   Standard nominal gear equations cannot be 3D printed directly without explicit backlash offsets
   tailored to printer nozzle extrusion physics.
      |
      v
[ Next Engineering Step ]
   Transition critical high-speed planetary stages from 3D-printed ABS to CNC-machined POM (Delrin)
   or precision nylon-injection molded gears.
```

---

## Challenge 03: Multi-Rotor Friction Compounding in Mark-5 (KECS)

```
[ Problem ]
   The 5-rotor Mark-5 prototype ("Project KECS") captured substantial total frontal area, but
   demanded significantly higher wind velocity to start spinning than the 3-rotor Mark-3 unit.
      |
      v
[ Investigation ]
   Mechanically linking five separate rotor pinions to a single central transmission gear creates
   five simultaneous friction nodes. Any minute angular misalignment across the aluminum frame
   caused uneven tooth loading and multiplied total parasitic friction.
      |
      v
[ Modification ]
   Conducted comparative benchmark tests between Configuration A (3-rotor), Configuration B (4-rotor),
   and Configuration C (5-rotor) as documented in the testing protocols.
      |
      v
[ Result ]
   Configuration B (4-rotor) provided the optimal empirical balance between captured frontal area
   and mechanical transmission complexity. Configuration C suffered from compounding mechanical drag.
      |
      v
[ Key Learning ]
   Simply adding more rotors to a common mechanical gear train has diminishing returns due to
   frictional compounding. Mechanical simplification is essential for low-power reliability.
      |
      v
[ Next Engineering Step ]
   Investigate independent generator per rotor versus centralized magnetic-gear power combining.
```

---

## Challenge 04: DC Bus Voltage Sizing (The 240V Trap)

```
[ Problem ]
   Early electrical architecture calculations explored scaling a commercial DFIG topology to 100 W,
   which resulted in an unusually high DC link voltage target (~240 V).
      |
      v
[ Investigation ]
   At 100 W output, a 240 V bus reduces rated current to just 0.356 A. Calculating the required
   LSC filter inductor via standard equations yielded an impractically massive value of 127 mH,
   along with severe converter switching inefficiencies at low power.
      |
      v
[ Modification ]
   Re-evaluated complete power electronics calculations for low-voltage direct current (LVDC) standards.
      |
      v
[ Result ]
   Selected a nominal 24 V DC system bus (operating current 3.2–4.2 A). Filter inductance dropped
   to standard commercial levels (< 2.5 mH) with standard compact passive components.
      |
      v
[ Key Learning ]
   High-voltage utility-scale wind turbine topologies (DFIG / 690V) cannot be linearly scaled down
   to micro-scale systems without encountering severe passive component scaling penalties.
      |
      v
[ Next Engineering Step ]
   Design a dedicated 24V synchronous buck-boost MPPT charge controller tailored for the 100W DC generator.
```

---

## Challenge 05: Field Wind Measurement & Dynamic Logging Gaps

```
[ Problem ]
   Early bench tests logged electrical voltage and current, but lacked synchronized, instantaneous
   wind speed measurements, making it impossible to determine true aerodynamic efficiency.
      |
      v
[ Investigation ]
   Natural outdoor wind fluctuates second-by-second. Comparing tests recorded on different days
   without simultaneous wind speed and rotor RPM logging produced inconsistent, unrepeatable data.
      |
      v
[ Modification ]
   Authored the comprehensive Intern Task Brief and implemented an ESP32 multi-sensor logging gateway
   integrating a cup anemometer on an interrupt pin, optical RPM sensing, and voltage/current ADCs.
      |
      v
[ Result ]
   Enabled simultaneous, timestamped data logging across all configurations into a unified CSV format,
   creating the empirical dataset necessary to train a baseline ML regression model.
      |
      v
[ Key Learning ]
   Wind turbine performance data is meaningless without simultaneous, high-frequency atmospheric wind logging.
      |
      v
[ Next Engineering Step ]
   Calibrate ESP32 datalogger against laboratory pitot-static reference tubes in the VNIT wind tunnel.
```

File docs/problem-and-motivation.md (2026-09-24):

# Problem & Project Motivation

## The Physical & Aerodynamic Challenge of Low Wind Speeds

Generating usable electrical power from low-velocity atmospheric wind is one of the most demanding fluid-mechanical and electromechanical challenges in renewable energy engineering.

### 1. Cubic Power Density Scaling
The instantaneous kinetic power available in an unconstrained wind stream of cross-sectional area $A$ is governed by the classical fluid power equation:

$$P_{\text{wind}} = \frac{1}{2} \rho A V^3$$

Where:
- $\rho \approx 1.225 \text{ kg/m}^3$ (sea-level dry air density, or $\approx 1.151 \text{ kg/m}^3$ under warm inland Indian conditions)
- $A = \pi r^2$ is the swept area ($\text{m}^2$)
- $V$ is the freestream wind velocity ($\text{m/s}$)

Because available power scales with the **cube of velocity ($V^3$)**, the energy density drops precipitously as wind speed decreases:

| Freestream Velocity $V$ | Wind Power Density ($\text{W/m}^2$ at $\rho = 1.151 \text{ kg/m}^3$) | Relative Available Energy |
| :---: | :---: | :---: |
| **$10.0\text{ m/s}$** (Coastal / Commercial wind site) | $575.5\text{ W/m}^2$ | $100.0\%$ |
| **$6.0\text{ m/s}$** (Moderate commercial threshold) | $124.3\text{ W/m}^2$ | $21.6\%$ |
| **$4.0\text{ m/s}$** (Typical inland breeze) | $36.8\text{ W/m}^2$ | $6.4\%$ |
| **$3.0\text{ m/s}$** (Inland average / target cut-in) | $15.5\text{ W/m}^2$ | $2.7\%$ |
| **$2.0\text{ m/s}$** (Gentle breeze / starting threshold) | $4.6\text{ W/m}^2$ | $0.8\%$ |

At $3.0\text{ m/s}$, an engineer has barely **$2.7\%$** of the power available at $10.0\text{ m/s}$ per square meter of swept aperture.

---

### 2. Aerodynamic Limitations at Low Reynolds Numbers
For small-scale wind turbines with blade chord lengths $c \sim 0.05\text{--}0.10\text{ m}$ operating at $2\text{--}4\text{ m/s}$, the chord Reynolds number:

$$Re = \frac{\rho V_{\text{rel}} c}{\mu} < 100,000$$

In this sub-critical Reynolds regime:
- Thick conventional airfoils (e.g., NACA 0012 or standard 4-digit series) suffer from extensive laminar separation bubbles, early boundary layer separation, and dramatic lift degradation.
- The lift-to-drag ratio ($C_L / C_D$) drops sharply, drastically lowering the aerodynamic driving torque.
- To produce positive starting torque without external motor kick-starting, the blades must incorporate high-camber, thin-profile geometries (such as the Selig S1223) that preserve attached boundary layers and high lift coefficients even at low Reynolds numbers.

---

### 3. The Electromechanical Starting Barrier
A wind turbine can only begin accelerating from standstill if the aerodynamic static torque ($Q_{\text{aero}}$) exceeds the total resisting static torque:

$$Q_{\text{aero}}(V, \theta) > Q_{\text{cogging}} + Q_{\text{bearing friction}} + Q_{\text{gearbox static friction}}$$

Standard commercial small-wind turbines often feature direct-drive permanent magnet generators (PMGs) designed for high rotational speeds. These generators exhibit substantial **magnetic cogging torque** caused by the interaction of rotor permanent magnets with stator iron teeth. Under low-wind conditions ($<5\text{ m/s}$), the small aerodynamic torque generated by stationary blades is unable to overcome this cogging threshold, causing the turbine to remain completely stalled despite the presence of air flow.

---

## Why Decentralized Low-Wind Harvesting Matters

### The Geographical Reality of Inland Electrification
Utility-scale wind farms are concentrated along coastal corridors, mountain passes, and offshore sites where annual average wind speeds consistently exceed $6.5\text{--}8.0\text{ m/s}$. However, billions of people—including large fractions of rural and semi-urban populations across the Indian subcontinent, Southeast Asia, sub-Saharan Africa, and the interior Americas—live in inland plains where average wind speeds range between **$2.0\text{ and } 4.5\text{ m/s}$**.

These communities have historically been excluded from wind energy because conventional small-wind hardware requires wind speeds exceeding $5.0\text{ m/s}$ just to reach cut-in.

### The Intermittency of Solar Photovoltaics
Rooftop solar PV has expanded dramatically, but it suffers from well-known temporal constraints:
1. **Zero nocturnal generation**: Off-grid rural clinics, residential lighting, boundary surveillance, and communication equipment consume steady power from sunset to sunrise.
2. **Monsoon and cloud attenuation**: Heavy cloud cover and particulate pollution can degrade instantaneous PV output by $60\text{--}80\%$.
3. **Diurnal wind complementarity**: In many inland regions, convective ground heating creates steady evening and night breezes, making micro-wind a natural physical complement to daytime solar generation.

---

## Project Motivation & Personal Origin

The inspiration for **PAWAN SHAKTI** grew out of hands-on observations at the **Visvesvaraya National Institute of Technology (VNIT), Nagpur**. 

Coming from an academic background in **Metallurgical and Materials Engineering**, founder **Koyaneni Yaswanth** recognized that while advanced power electronics and multi-megawatt commercial turbines receive intensive research attention, small-scale micro-wind systems suitable for residential rooftops in low-wind areas remain fundamentally limited by basic mechanical transmission bottlenecks, poor low-Reynolds blade design, and cost.

> *"I wanted to investigate whether a compact mechanical transmission system—specifically coaxial planetary gearing and multi-rotor clustering—could help make small-scale wind generation mechanically feasible and economically practical in lower-wind conditions where standard turbines remain stalled."*

Rather than relying purely on theoretical simulations or commercial off-the-shelf assemblies, Yaswanth initiated a direct experimental program: modeling custom high-lift airfoils in Autodesk Fusion 360, additive manufacturing modular prototypes with integrated 2.5 module gearing, evaluating structural integrity in ANSYS, and validating physical rotation and electrical generation on the test bench and in VNIT's research facilities under the mentorship of Dr. Jawahar Bhukya.

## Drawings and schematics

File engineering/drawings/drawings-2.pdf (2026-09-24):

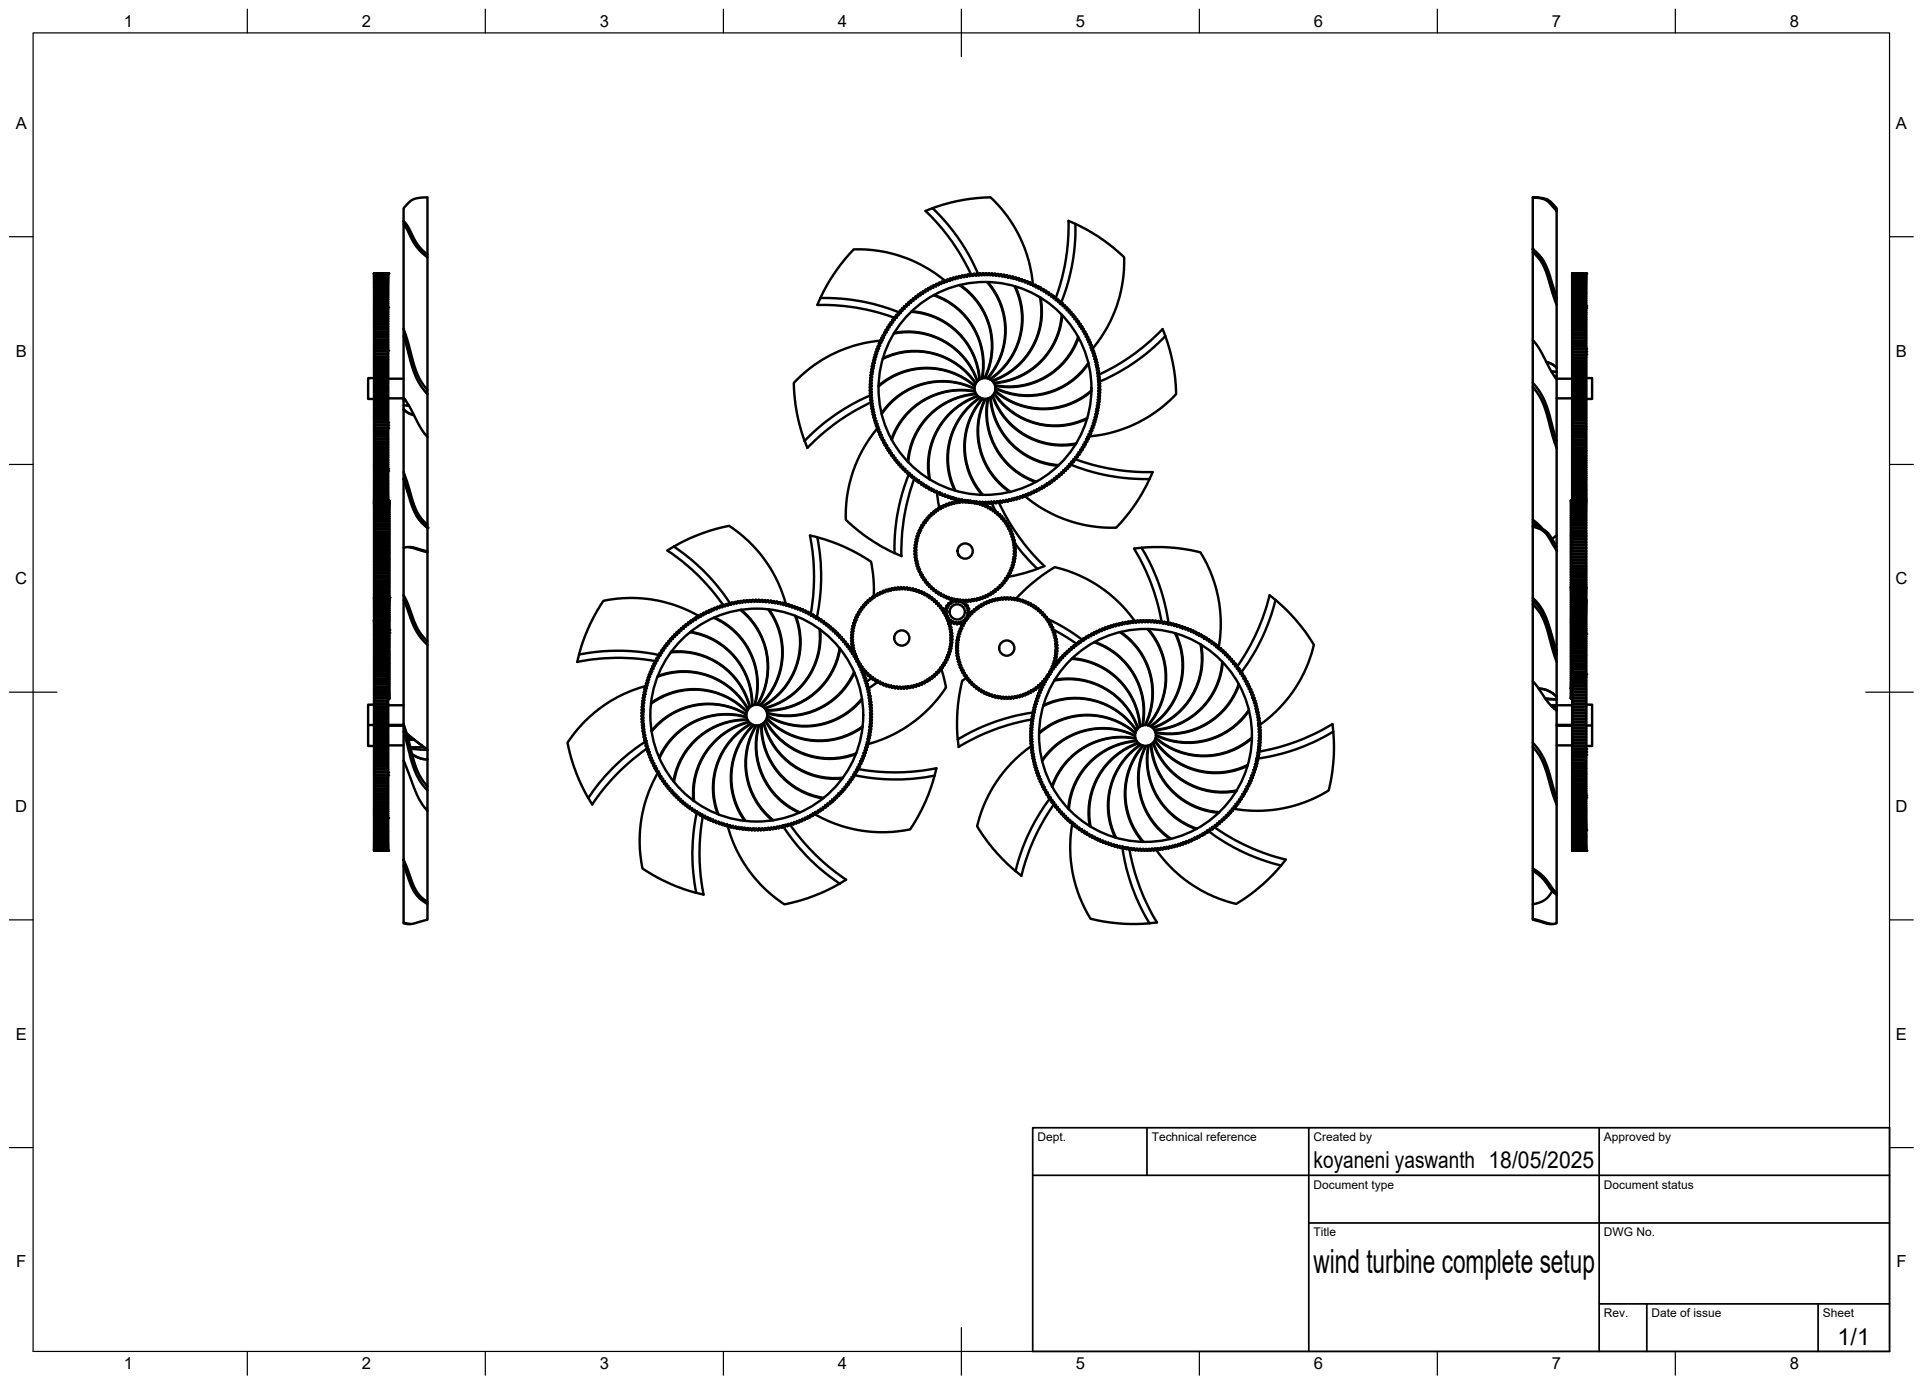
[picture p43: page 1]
Dept.; Technical reference; Created by; Approved by; Document type; Document status; Title; DWG No.; Rev.; Date of issue; Sheet; koyaneni yaswanth

wind turbine complete setup

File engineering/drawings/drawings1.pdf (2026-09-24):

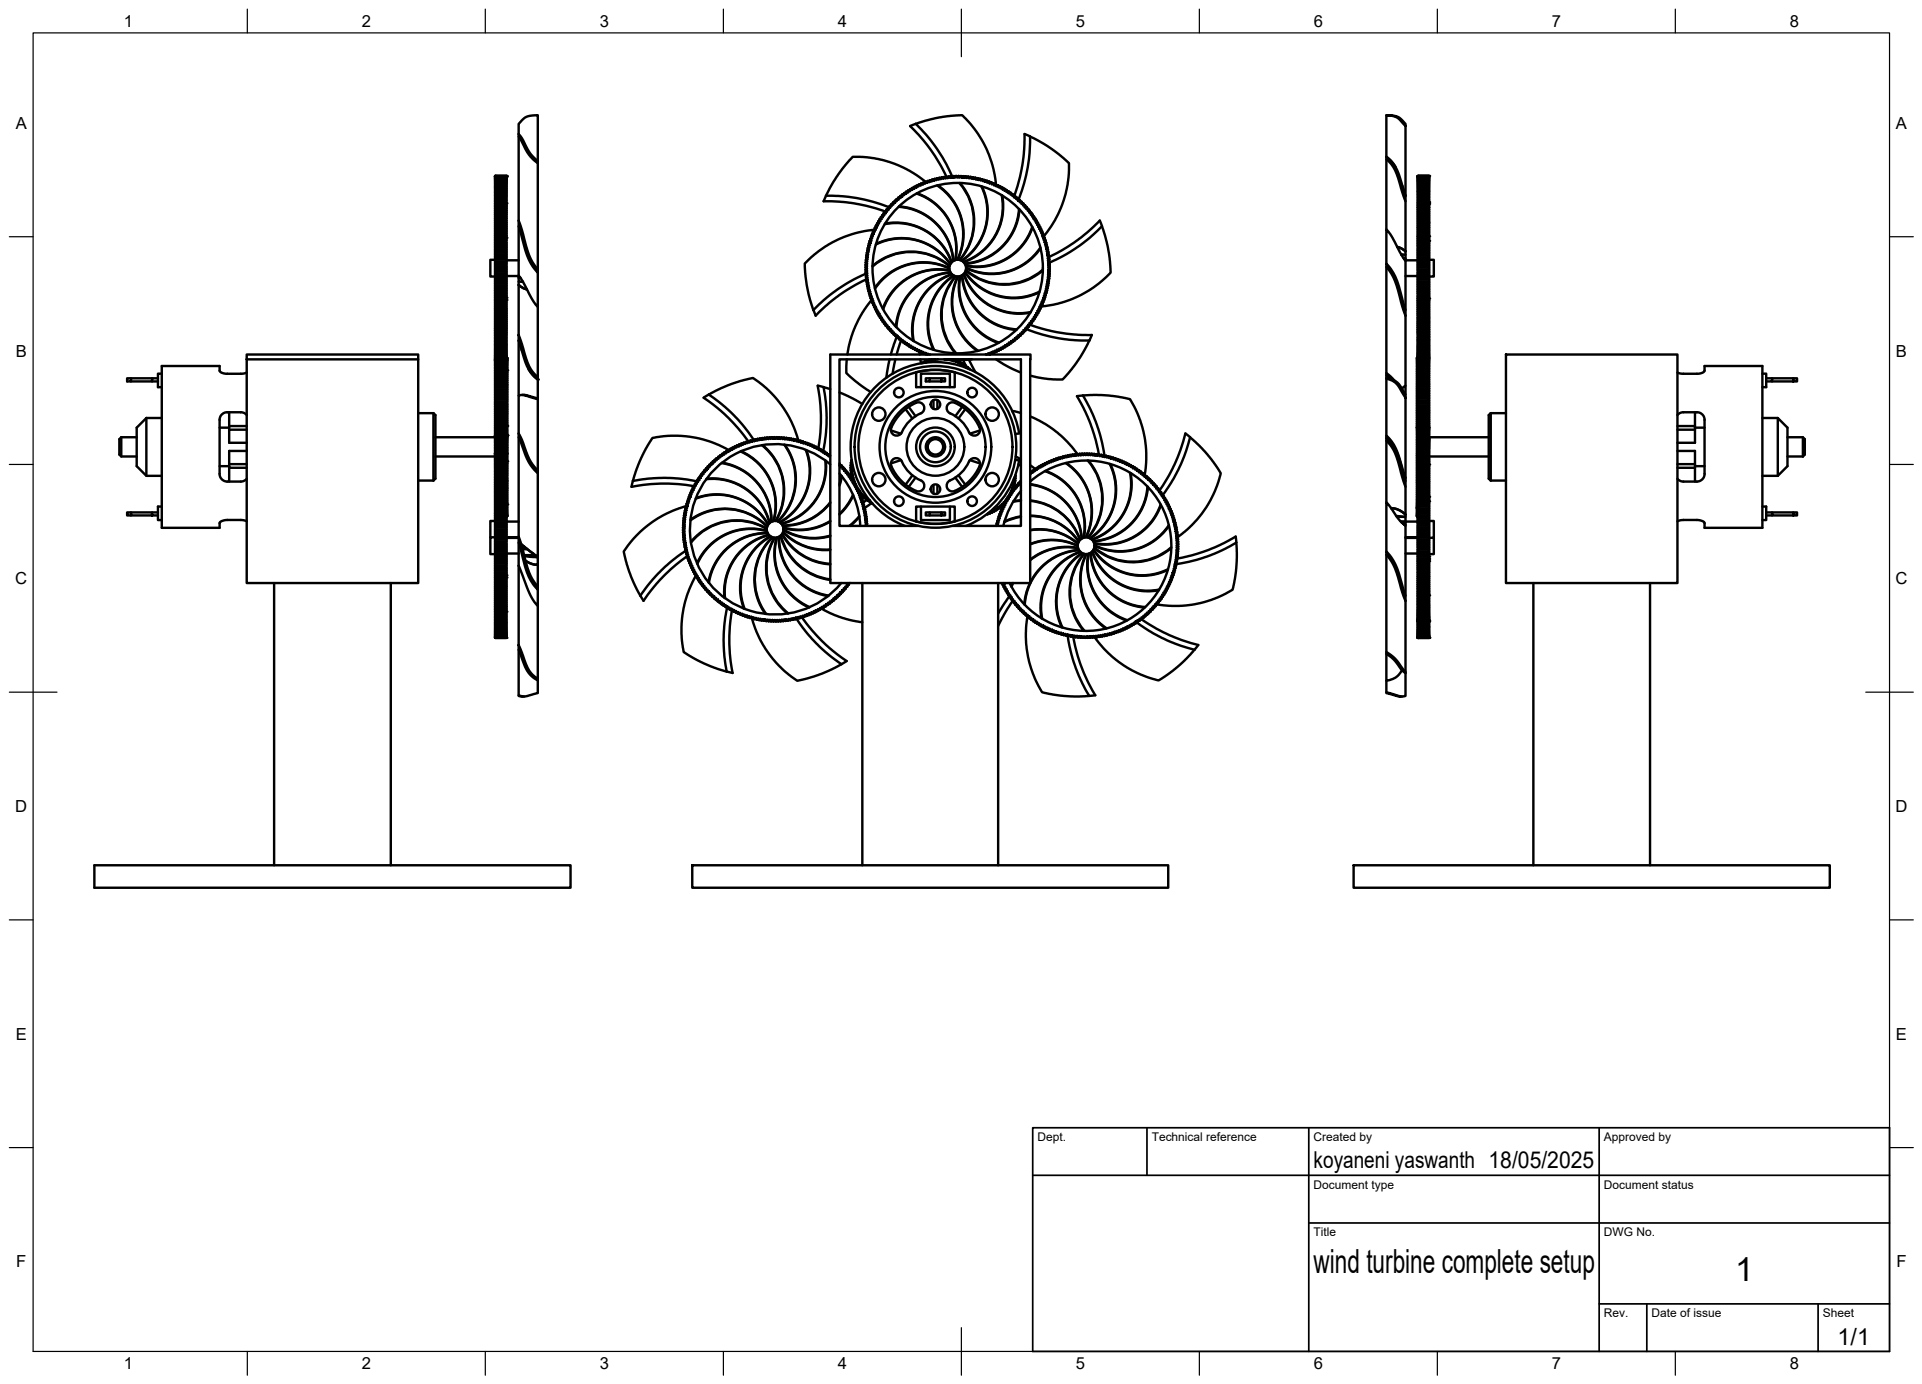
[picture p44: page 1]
Dept.; Technical reference; Created by; Approved by; Document type; Document status; Title; DWG No.; Rev.; Date of issue; Sheet; wind turbine complete setup; koyaneni yaswanth

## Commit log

2026-09-24 feat: transform repository into evidence-first engineering research portfolio
    - Completely rewrite README.md with technical parameters, equations, and prototype evidence
    - Document S1223 airfoil selection, multi-rotor aerodynamics, and low-Re physics
    - Add kinematics and mechanical loss analysis for 1:10 planetary step-up gearbox
    - Document ANSYS FEA structural boundary conditions and simulation limits
    - Compile empirical test logs and comparative benchmarks across Mark-3, 4, and 5 prototypes
    - Add ESP32 multi-sensor logging and rotation protocol
    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
    [30cm_2.5mod_s1223prof_gear.3mf, 30cm_2.5mod_s1223prof_gear1.3mf, Configuration 2.stl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]
2026-11-10 feat(platform): implement Pawan Shakti TRL 4 website, interactive 3D CAD, calculators, CRM, telemetry API, RLS schema & E2E verification
2026-11-11 feat(visuals): add cinematic 3D wind turbine hero, exploded assembly, Willis planetary gearbox, energy flow & Option A/B comparison
